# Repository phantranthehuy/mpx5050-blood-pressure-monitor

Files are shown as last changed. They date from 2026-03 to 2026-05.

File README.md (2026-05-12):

# 🩺 Digital Oscillometric Blood Pressure Monitor

> An academic research project focused on designing and developing a digital blood pressure monitor using the **MPX5050** pressure sensor and the **Oscillometric Method**.

## 📖 Table of Contents
- [About the Project](#about-the-project)
- [Key Features](#key-features)
- [Team Members](#team-members)
- [System Architecture](#system-architecture)
- [Technology Stack](#technology-stack)
- [Repository Structure](#repository-structure)
- [Getting Started](#getting-started)
- [License](#license)

## 🔬 About the Project
This repository contains the hardware schematics, embedded C firmware, and signal processing algorithms for an automated blood pressure monitor. 

The system operates based on the **Oscillometric Method**. It extracts tiny pressure oscillations (AC component) superimposed on the static cuff pressure (DC component) during the deflation phase. By analyzing the envelope of these oscillations, the system calculates the Mean Arterial Pressure (MAP), Systolic Pressure (SYS), Diastolic Pressure (DIA), and Heart Rate (BPM).

## ✨ Key Features
- **Automated Cuff Control:** Smooth inflation and linear deflation using a DC pump and a solenoid valve.
- **High-Precision Sensing:** Utilizes the MPX5050DP sensor with a custom Analog Front-End (AFE) for signal amplification and band-pass filtering (0.5Hz - 5Hz).
- **DSP Algorithms:** Implements digital filtering and envelope detection algorithms to accurately identify blood pressure parameters.
- **User Interface:** Real-time pressure monitoring and final result display via an LCD/OLED screen.

## 👥 Team Members
| Name | Role | Responsibilities |
| :--- | :--- | :--- |
| **Phan Tran The Huy** | **Project Manager & Hardware Lead** | Overall project management, Altium/KiCad schematic & PCB design, and hardware integration. |
| **Tran Nhat Ly** | **Mechanical & UI/UX Engineer** | 3D enclosure design, mechanical assembly, component sourcing, and UI programming. |
| **Nguyen Huy Hoang** | **DSP Algorithm & Research Lead** | Signal processing research (Kalman/FIR filters), data analysis, and technical documentation. |
| **Cao Hoang Tung** | **Embedded Software Engineer** | STM32 C programming, Pump/Valve driver implementation, and translating MATLAB/Python algorithms into embedded C. |

## 📐 System Architecture

The core of the system relies on capturing and separating the pressure signals:

## 🛠 Technology Stack
- **Microcontroller:** STM32 Series
- **Firmware:** C (STM32 HAL, CMake) trong `firmware/stm32-hal-cmake/`; tùy chọn C/C++ Arduino (STM32duino) trong `firmware/stm32-arduino-pio/`.
- **Development Environment:** VS Code with STM32CubeIDE Extension (HAL) hoặc VS Code + PlatformIO (Arduino, `firmware/stm32-arduino-pio/`).
- **Hardware Design:** Altium Designer / KiCad
- **Simulation Tools:** LTSpice (Analog filtering), Python/MATLAB (Algorithm verification)

## 📂 Repository Structure
```text
📦 mpx5050-blood-pressure-monitor
 ┣ 📂 Algorithms      # Python/MATLAB scripts for algorithm simulation & signal filtering
 ┣ 📂 Docs            # Datasheets, academic papers, and technical reports
 ┣ 📂 firmware        # stm32-hal-cmake (CMake+HAL) + stm32-arduino-pio (PlatformIO Arduino)
 ┣ 📂 Hardware        # Schematics, PCB layouts, and Bill of Materials (BOM)
 ┣ 📂 Mechanical      # 3D models and CAD files for the device enclosure
 ┣ 📜 .gitignore      # Ignored files for STM32, VS Code, and EDA tools
 ┣ 📜 LICENSE         # MIT License
 ┗ 📜 README.md       # Project documentation
```

## 🚀 Getting Started

### Prerequisites
- **VS Code** installed with the `C/C++` and `STM32 VS Code Extension`.
- **STM32CubeMX** (for modifying microcontroller pinouts/clocks).
- **Git** for version control.

### Installation & Build
1. **Clone the repository:**
   ```bash
   git clone https://github.com/your-username/mpx5050-blood-pressure-monitor.git
   ```
2. **Open the firmware (HAL / CMake):**
   Open the `firmware/stm32-hal-cmake` directory in VS Code (CMake + STM32 HAL).
3. **Optional — Arduino framework (same MCU):**
   Open `firmware/stm32-arduino-pio` in VS Code with the PlatformIO extension, or run `pio run` from that folder (see `firmware/stm32-arduino-pio/README.md`).
4. **Compile:**
   Press `Ctrl + Shift + B` (or use the STM32 extension build button) to compile the C code and generate the `.elf` / `.hex` files.
5. **Flash to MCU:**
   Connect your ST-Link debugger and click `Run > Start Debugging` (F5) to flash the firmware onto the STM32.

## ⚖️ License
This project is licensed under the **MIT License** - see the [LICENSE](LICENSE) file for details. Designed for academic and research purposes.

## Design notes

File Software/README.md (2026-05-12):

# Software — tài liệu host & WebApp

Thư mục này chứa tài liệu giao thức UART dùng chung với firmware và ứng dụng web đọc **USB TTL** (Web Serial).

## WebApp (Vite + TypeScript)

**Trình duyệt:** Chrome hoặc Edge (Web Serial). Phục vụ qua `http://localhost` hoặc HTTPS.

```bash
cd webapp
npm install
npm run dev
```

- Giao thức `S/A/E`, `T` và **MAA** trên host: [`pc-bridge.md`](pc-bridge.md), [`algorithm.md`](algorithm.md).
- Nút **Hủy** gửi `ABORT`; ô **SAF test** gửi `T,...` (clamp theo SAF đã cấu hình trên MCU / form, mặc định 175 mmHg). Sau kết nối, WebApp gửi `SAF` / `SAFH` / `HIGH` theo form **MCU — UART**.
- **Firefox/Safari** không có Web Serial: có thể dùng bridge TCP như gợi ý trong [`pc-bridge.md`](pc-bridge.md) (`socat`/nhỏ script đọc COM và WebSocket) rồi mở rộng webapp sau nếu cần.

## Firmware (tham chiếu)

Có hai biến thể cho **STM32F103C8 Blue Pill**, cùng chân và giao thức serial với WebApp:

| Thư mục | Công cụ | Ghi chú |
|---|---|---|
| [`../firmware/stm32-hal-cmake/`](../firmware/stm32-hal-cmake/) | CMake + STM32 HAL | Bản gốc trong repo; build theo [`../firmware/stm32-hal-cmake/README.md`](../firmware/stm32-hal-cmake/README.md). |
| [`../firmware/stm32-arduino-pio/`](../firmware/stm32-arduino-pio/) | PlatformIO + **Arduino** framework | `Wire` / `Serial` / `HardwareTimer`; xem [`../firmware/stm32-arduino-pio/README.md`](../firmware/stm32-arduino-pio/README.md). |

### Build & nạp (HAL — CMake)

```bash
cd ../firmware/stm32-hal-cmake
cmake --preset Debug
cmake --build build/Debug
```

### Build & nạp (Arduino — PlatformIO)

```bash
cd ../firmware/stm32-arduino-pio
pio run
pio run -t upload
pio device monitor -b 115200
```

Cần [PlatformIO Core](https://platformio.org/install) và ST-Link (hoặc đổi `upload_protocol` trong [`../firmware/stm32-arduino-pio/platformio.ini`](../firmware/stm32-arduino-pio/platformio.ini)).

### Cấu hình phần cứng

Chân mặc định xem [`../firmware/stm32-hal-cmake/Core/Inc/board_config.h`](../firmware/stm32-hal-cmake/Core/Inc/board_config.h) (HAL) hoặc `board_config.h` trong project Arduino (cùng map chân):

- UART1 **115200**: PA9 TX, PA10 RX  
- I2C1: PB6 SCL, PB7 SDA (ADS1115 `0x48`)  
- PWM TIM3: PA6 bơm, PA7 van  
- Nút (active LOW): PA3 Start, PA4 Stop, PA5 High-mode  
- LED schematic D401/D402/D403: **PB13 đỏ**, **PB14 xanh**, **PB15 vàng**

Hiệu chỉnh `PRESSURE_ADC_OFFSET_COUNTS` và `PRESSURE_ADC_SCALE_MMHG_PER_COUNT` theo MPX5050 + đồng hồ áp.

## Giao tiếp WebApp / serial

Chi tiết khung tin, band-pass 0.5–5 Hz trên host, và luồng `P_sys_est` → lệnh `T,...`: [**pc-bridge.md**](pc-bridge.md).

## Kiểm thử

Checklist mở rộng: [**TESTING.md**](TESTING.md), tham chiếu [`testcase.md`](testcase.md).

## LED (HMI)

Logic không chặn theo [`LED_Algorithm.md`](LED_Algorithm.md); phần C trong firmware HAL: [`../firmware/stm32-hal-cmake/Core/Inc/led_hmi.h`](../firmware/stm32-hal-cmake/Core/Inc/led_hmi.h), [`../firmware/stm32-hal-cmake/Core/Src/led_hmi.c`](../firmware/stm32-hal-cmake/Core/Src/led_hmi.c), ánh xạ trạng thái trong [`../firmware/stm32-hal-cmake/Core/Src/bp_fsm.c`](../firmware/stm32-hal-cmake/Core/Src/bp_fsm.c) (`bp_fsm_led_hmi_state`). Bản Arduino dùng cùng thuật toán LED trong `src/led_hmi.cpp`.

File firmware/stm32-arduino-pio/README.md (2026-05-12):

# Firmware Arduino — STM32F103 Blue Pill (PlatformIO)

Đây là **port song song** với bản CMake + HAL trong [`../stm32-hal-cmake/`](../stm32-hal-cmake/): cùng **STM32F103C8T6**, cùng map chân và **cùng giao thức UART** với WebApp/PC (xem [`../stm32-hal-cmake/docs/pc-bridge.md`](../stm32-hal-cmake/docs/pc-bridge.md)).

**Lưu ý:** Khi đổi thuật toán đo / FSM, nên coi bản **HAL CMake** là chuẩn tham chiếu rồi đồng bộ sang thư mục này (hoặc ngược lại — nhưng tránh chỉ sửa một bên).

## Công cụ

- [PlatformIO Core](https://platformio.org/install) (`python3 -m pip install --user platformio`)
- Nạp: **ST-Link** (mặc định `upload_protocol = stlink` trong [`platformio.ini`](platformio.ini)); có thể đổi sang `serial` nếu dùng bootloader UART.

## Build & nạp

```bash
cd firmware/stm32-arduino-pio
python3 -m platformio run
python3 -m platformio run -t upload
python3 -m platformio device monitor -b 115200
```

## Map chân (trùng HAL)

Định nghĩa trong [`src/board_pins.h`](src/board_pins.h) và hằng số áp suất trong [`src/board_config.h`](src/board_config.h):

| Chức năng | Chân |
|---|---|
| UART1 115200 | PA9 TX, PA10 RX (`Serial`) |
| I2C1 (ADS1115 `0x48`) | PB6 SCL, PB7 SDA (`Wire`) |
| PWM bơm / van | PA6, PA7 (`analogWrite`, 1 kHz) |
| Nút (active LOW, pull-up) | PA3 Start, PA4 Stop, PA5 High |
| LED | PB13 đỏ, PB14 xanh, PB15 vàng |

## Khác biệt so với bản HAL

- **ADS1115:** driver dùng `Wire` (địa chỉ 7-bit), không dùng `HAL_I2C_*`.
- **UART:** `Serial` + `uart_proto_poll_rx()` trong vòng lặp (polling), tương đương luồng lệnh `T,...` / `ABORT` / `DR,...` / `EARLYEND` khi đã đồng bộ với bản HAL.
- **100 Hz:** `HardwareTimer` trên **TIM2** (`setOverflow(100, HERTZ_FORMAT)`).
- **PWM:** `analogWriteFrequency(1000)` (toàn cục trên core STM32duino) + `analogWriteResolution(10)` + `analogWrite` — tương đương duty 0–100 % của HAL.

## Giao thức host

Giữ nguyên định dạng dòng `S,...`, `A,...`, `E,...` và lệnh `T,<mmHg>` như tài liệu `pc-bridge.md` ở bản HAL. Thêm: **`DR,<mmHg/s>`** (tốc độ xả chậm đo, clamp theo `DEFLATE_SLOW_RATE_UART_*` trong `board_config.h`, hiện 2.5–10.0 mmHg/s) và **`EARLYEND`** (kết thúc xả chậm sớm → xả nhanh, chỉ trong pha đo). Dòng **`S,...`** đầy đủ kết thúc bằng **`,<dp_centi>`** — `dp_centi = round(dp/dt mmHg/s × 100)` (âm khi áp giảm); WebApp parse thành `dpMmHgPerS`.

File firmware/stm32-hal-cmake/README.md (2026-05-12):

# Firmware — máy đo huyết áp oscillometric (STM32F103 Blue Pill)

Project **STM32Cube / CMake** (HAL): đọc áp **ADS1115** (I2C), điều khiển **bơm/van PWM**, stream **100 Hz** qua UART cho WebApp/PC, SAF mặc định **175 mmHg** (có thể đổi UART `SAF` / `SAFH`) và **Emergency Stop** cục bộ.

## Build & nạp

Cần **CMake ≥ 3.22**, **GNU Arm Embedded Toolchain** (`arm-none-eabi-gcc`), và **Git** (lần cấu hình đầu CMake sẽ clone HAL/CMSIS vào `third_party/`).

```bash
cd firmware/stm32-hal-cmake
cmake --preset Debug
cmake --build build/Debug
```

File nhị phân: `build/Debug/bp_monitor.bin`, ELF `build/Debug/bp_monitor`.

**STM32CubeIDE for VS Code:** mở folder `firmware/stm32-hal-cmake`, chọn preset **Debug** hoặc **Release**, chạy CMake configure/build trong extension theo [First project creation](https://dev.st.com/stm32cube-docs/stm32cubeide-vscode/1.0.1/en/docs/markup/getting_started/first_project_creation.html).

**Bản Arduino (PlatformIO, thư viện Wire/Serial):** xem [`../stm32-arduino-pio/README.md`](../stm32-arduino-pio/README.md).

**Nạp chip:** dùng `stm32flash`, OpenOCD, hoặc STM32CubeProgrammer tới địa chỉ flash `0x08000000`, ví dụ:

```bash
stm32flash -w build/Debug/bp_monitor.bin -v -g 0x0 /dev/ttyUSB0   # tuỳ adapter UART bootloader
```

**UART serial:** `115200 8N1` trên USART1 (PA9/PA10).

### STM32F103C8T6 (Blue Pill)

Không cần đổi macro biên dịch: ST dùng **`STM32F103xB`** trong CMSIS cho cả **C8** và **CB** (file chip là `stm32f103xb.h`). Điều quan trọng là **kích thước Flash trong linker**:

| MCU | Flash | Việc cần làm |
|-----|---|---|
| **STM32F103C8T6** | 64 KiB | Giữ nguyên `cmake/STM32F103C8Tx_FLASH.ld` (đã cấu hình sẵn). |
| **STM32F103CB…** | 128 KiB | Đổi `LENGTH` Flash trong linker script thành `128K` (hoặc dùng script ST cho RB/CB 128K). |

## Cấu hình phần cứng

Chân mặc định xem [`Core/Inc/board_config.h`](Core/Inc/board_config.h):

- UART1 **115200**: PA9 TX, PA10 RX  
- I2C1: PB6 SCL, PB7 SDA (ADS1115 `0x48`)  
- PWM TIM3: PA6 bơm, PA7 van  
- Nút (active LOW): PA3 Start, PA4 Stop, PA5 High-mode  
- LED schematic D401/D402/D403: **PB13 đỏ**, **PB14 xanh**, **PB15 vàng**

Hiệu chỉnh `PRESSURE_ADC_OFFSET_COUNTS` và `PRESSURE_ADC_SCALE_MMHG_PER_COUNT` theo MPX5050 + đồng hồ áp.

## Giao tiếp WebApp / serial

Chi tiết khung tin, band-pass 0.5–5 Hz trên host, và luồng `P_sys_est` → lệnh `T,...`: [**docs/pc-bridge.md**](docs/pc-bridge.md).

## Kiểm thử

Checklist mở rộng: [**TESTING.md**](TESTING.md), tham chiếu [`testcase.md`](testcase.md).

## LED (HMI)

Logic không chặn theo [`LED_Algorithm.md`](LED_Algorithm.md); code: [`Core/Inc/led_hmi.h`](Core/Inc/led_hmi.h), [`Core/Src/led_hmi.c`](Core/Src/led_hmi.c), ánh xạ trạng thái trong [`Core/Src/bp_fsm.c`](Core/Src/bp_fsm.c) (`bp_fsm_led_hmi_state`).

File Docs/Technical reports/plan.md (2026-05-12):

# Dàn ý báo cáo — Máy đo huyết áp oscillometric (MPX5050 + STM32)

## Thông tin (điền vào `Project_report/main.tex`)

- **Môn / loại báo cáo:** Đồ án / báo cáo môn học EE3037 (điều chỉnh nếu khác).
- **Đề tài:** Thiết kế máy đo huyết áp điện tử phương pháp oscillometric dựa trên cảm biến áp MPX5050, ADC ADS1115 và vi điều khiển STM32F103; phần mềm host Web Serial để lọc tín hiệu và tính MAP/SBP/DBP (MAA).
- **GVHD:** *(điền tên)*  
- **SVTH / MSSV:** *(điền)*  

## Cấu trúc chương (ánh xạ file LaTeX)

1. **Chương 1 — Giới thiệu** (`chap1.tex`)  
   - Tổng quan bài toán đo huyết áp không xâm lấn.  
   - Phương pháp oscillometric, vai trò cuff–cảm biến–MCU–host.  
   - Nhiệm vụ đề tài (phần cứng, firmware, WebApp, an toàn SAF).  
   - Bố cục báo cáo.

2. **Chương 2 — Phần cứng** (`chap2.tex`)  
   - Sơ đồ khối: MPX5050 → điều kiện tín hiệu → ADS1115 (I2C) → STM32.  
   - Điều khiển bơm/van PWM; nút Start/Stop/High; LED trạng thái.  
   - Tham chiếu schematic/PCB (in từ KiCad — file ảnh/PDF trong `images/`).  
   - Giới hạn an toàn: trần áp 280 mmHg (SAF).

3. **Chương 3 — Firmware và thuật toán** (`chap3.tex`)  
   - Kiến trúc PlatformIO / STM32Cube; đọc áp; stream UART 100 Hz (`S,...`).  
   - FSM đo: bơm chậm, lệnh `T,...` từ host, xả chậm đo.  
   - Cơ sở MAA trên host: envelope, MAP, hệ số \(r_s\), \(r_d\) cho SBP/DBP; band-pass 0,5–5 Hz (theo tài liệu nội bộ).  
   - Hiệu chỉnh offset/scale ADC → mmHg.

4. **Chương 4 — Phần mềm host và kiểm thử** (`chap4.tex`)  
   - WebApp (Vite + TypeScript), Web Serial; giao thức `A/E/T/ABORT`.  
   - Luồng `P_\mathrm{sys\,est}` → `T,...`; clamp SAF.  
   - Checklist kiểm thử (UART, LED, SAF, leak timeout).

5. **Kết luận** (`ketluan.tex`)  
   - Kết quả đạt được; hạn chế (hiệu chỉnh, chỉ số MAA cố định); hướng phát triển.

6. **Tài liệu tham khảo** (`tlthamkhao.tex`)  
   - Datasheet NXP MPX5050, TI ADS111x, RM/STM32F103; tài liệu oscillometry / MAA nếu có.

## Hình ảnh đính kèm trong `Project_report/images/`

- `logo-bku.png` — logo trường (bìa).  
- `Print.pdf` — bản in schematic/board (nếu có).  
- `webapp-hero.png` — minh họa giao diện WebApp (tùy chọn).

## Biên dịch

Dùng **XeLaTeX** (class có `fontspec`). Ví dụ: `latexmk -xelatex main.tex` trong thư mục `Project_report`.

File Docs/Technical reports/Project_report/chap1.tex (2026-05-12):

%===============================================================
% chap1.tex — Chương 1: Giới thiệu
%===============================================================
\pagestyle{fancy}
\chapter{GIỚI THIỆU}

\section{Tổng quan đề tài}
Đo huyết áp động mạch là một trong các chỉ số sinh lý quan trọng trong chẩn đoán và theo dõi bệnh tim mạch. Trong thực hành lâm sàng cổ điển, phương pháp Korotkoff kết hợp máy đo thủy ngân và ống nghe cho phép xác định áp tâm thu (SBP) và áp tâm trương (DBP) nhờ âm thanh nghe được khi xả khí vòng bít. Máy đo điện tử hiện đại phổ biến thay thế tai nghe bằng việc phân tích dao động áp suất nhỏ trên nền áp suất bao (\textit{oscillometric}), phù hợp với phần cứng chi phí thấp và tái lập trình.

Đề tài xây dựng một nguyên mẫu máy đo oscillometric với các đặc điểm sau:
\begin{itemize}\itemsep0pt \parskip0pt \parsep0pt
	\item \textbf{Cảm biến áp:} MPX5050GP (đầu ra tương tự thuận tiện khuếch đại/đọc ADC).
	\item \textbf{Bộ chuyển đổi số:} ADS1115 độ phân giải 16-bit, giao tiếp I\textsuperscript{2}C với STM32F103.
	\item \textbf{Điều khiển khí nén:} bơm và van được điều chỉnh bằng PWM để đạt tốc độ bơm và xả mong muốn.
	\item \textbf{An toàn:} giới hạn áp suất cực đại 280~mmHg (SAF), dừng khẩn cấp nút cứng và lệnh serial \texttt{ABORT}.
	\item \textbf{Host:} WebApp đọc cổng serial (Web Serial), hiển thị sóng áp và thực hiện lọc số + thuật toán MAA để suy ra MAP, SBP, DBP.
\end{itemize}

\section{Nhiệm vụ đề tài}
\noindent\textbf{Nội dung 1: Phần cứng và bo mạch (OscilloBP Monitor).}\\
\vspace{-0.6cm}
\begin{itemize}\itemsep0pt \parskip0pt \parsep0pt
	\item \textbf{Mục tiêu:} Hoàn thiện mạch đo áp, MCU, điều khiển bơm/van, nút nhấn và LED trạng thái theo schematic/PCB trong kho mã.
	\item \textbf{Ý tưởng thực hiện:} MPX5050 cấp điện áp tỉ lệ áp suất; ADS1115 lấy mẫu ổn định hơn ADC nội Blue Pill; STM32 điều phối FSM đo và streaming UART.
\end{itemize}
\vspace{-0.2cm}

\noindent\textbf{Nội dung 2: Firmware STM32 (PlatformIO / STM32Cube).}\\
\vspace{-0.6cm}
\begin{itemize}\itemsep0pt \parskip0pt \parsep0pt
	\item \textbf{Mục tiêu:} Đọc áp liên tục trong các pha đo, điều khiển bơm/van theo tốc độ đặt trước, đồng bộ với lệnh \texttt{T,...} từ host.
	\item \textbf{Ý tưởng thực hiện:} Máy trạng thái gồm các pha bơm chậm (nghe dao động), ramp margin, xả chậm đo, xả nhanh kết thúc hoặc an toàn; định dạng khung \texttt{S,<seq>,<t\_ms>,<p\_mmHg>} và thông báo \texttt{A,...}, \texttt{E,...}.
\end{itemize}
\vspace{-0.2cm}

\noindent\textbf{Nội dung 3: Phần mềm host và kiểm chứng.}\\
\vspace{-0.6cm}
\begin{itemize}\itemsep0pt \parskip0pt \parsep0pt
	\item \textbf{Mục tiêu:} Hiển thị thời gian thực, lọc dao động, tính MAP/SBP/DBP bằng MAA; kiểm thử UART, LED và SAF.
	\item \textbf{Ý tưởng thực hiện:} Band-pass 0{,}5--5~Hz trên chuỗi áp; phát hiện dao động đầu tiên trong pha bơm chậm để ước lượng \texttt{P\_sys\_est} và gửi \texttt{T,P\_sys\_est+margin}.
\end{itemize}

\section{Bố cục báo cáo}
Ngoài phần đầu (tóm tắt, mục lục, danh mục hình/bảng và viết tắt), báo cáo gồm bốn chương chính và phần kết luận. \textbf{Chương 2} trình bày kiến trúc phần cứng và hình ảnh schematic/in PCB. \textbf{Chương 3} mô tả firmware, giao thức serial và cơ sở thuật toán oscillometric/MAA được triển khai trên host. \textbf{Chương 4} giới thiệu WebApp và checklist kiểm thử. \textbf{Kết luận} tóm tắt kết quả, hạn chế và hướng phát triển.

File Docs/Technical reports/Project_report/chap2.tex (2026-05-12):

%===============================================================
% chap2.tex — Phần cứng
%===============================================================
\pagestyle{fancy}
\chapter{CƠ SỞ PHẦN CỨNG}

\section{Sơ đồ khối chức năng}
Hệ thống gồm các khối sau:
\begin{enumerate}\itemsep0pt
	\item \textbf{Vòng bít và đường khí nối:} chứa áp suất làm xẹp động mạch và truyền áp tới cảm biến.
	\item \textbf{Cảm biến MPX5050:} chuyển áp suất tương đối thành điện áp tương tự (khảo sát đường đặc tuyến trong datasheet).
	\item \textbf{ADC ADS1115:} chuyển đổi điện áp với độ phân giải 16-bit; giao tiếp I\textsuperscript{2}C với MCU (địa chỉ thiết bị mặc định 0x48 khi chân ADDR nối GND).
	\item \textbf{Vi điều khiển STM32F103 (Blue Pill):} đọc ADS1115, điều khiển PWM bơm và van, đọc nút nhấn, điều khiển LED và truyền thông UART.
	\item \textbf{Nguồn và điều kiện tiếp đất:} đảm bảo MPX5050 và ADC có tham chiếu ổn định; layout PCB tuân thủ khuyến nghị của nhà sản xuất để giảm nhiễu đo lường.
\end{enumerate}

\section{Giao tiếp và chân cắm chính}
Theo cấu hình mặc định trong firmware (\texttt{board\_config.h}):
\begin{itemize}\itemsep0pt
	\item UART1 115200~bps: PA9 (TX), PA10 (RX).
	\item I2C1: PB6 (SCL), PB7 (SDA) nối ADS1115.
	\item Timer 3 PWM: PA6 kênh bơm, PA7 kênh van (điều chỉnh duty để servo tốc độ bơm/xả).
	\item Nút tác động mức thấp (kéo lên nội bộ): PA3 Start, PA4 Stop, PA5 High-mode.
	\item LED báo hiệu: PB13 đỏ, PB14 xanh, PB15 vàng (ánh xạ trạng thái đo và cảnh báo).
\end{itemize}

\section{An toàn và giới hạn vật lý}
\begin{itemize}\itemsep0pt
	\item Trần áp \textbf{280~mmHg}: firmware ngắt bơm và mở van để xả nhanh khi vượt ngưỡng hoặc khi người dùng nhấn Stop/\texttt{ABORT}.
	\item Timeout rò khí: nếu áp không tăng đủ trong khoảng thời gian đặt (ví dụ rò đường khí), FSM báo lỗi cảm biến/rò và chuyển LED đỏ báo lỗi.
\end{itemize}

\section{Schematic và PCB}
Thiết kế schematic và bản vẽ PCB được hoàn thiện trong dự án KiCad \textit{OscilloBP Monitor}. Hình~\ref{fig:schematic-print} trích bản in PDF trong kho mã (có thể thay bằng ảnh độ phân giải cao hơn khi cần in báo cáo).

\begin{figure}[htbp]
	\centering
	
	\caption{Bản in schematic/board (trích từ dự án KiCad OscilloBP Monitor).}
	\label{fig:schematic-print}
\end{figure}

\section{Nhiệm vụ hiệu chỉnh phần cứng}
Để đọc mmHg chính xác từ ADC, cần hiệu chỉnh hai tham số trong firmware: \texttt{PRESSURE\_ADC\_OFFSET\_COUNTS} và \texttt{PRESSURE\_ADC\_SCALE\_MMHG\_PER\_COUNT} so với đồng hồ áp chuẩn hoặc nguồn áp đã biết. Đây là bước bắt buộc trước khi đánh giá lâm sàng.

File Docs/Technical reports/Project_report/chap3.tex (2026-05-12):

%===============================================================
% chap3.tex — Firmware và thuật toán
%===============================================================
\pagestyle{fancy}
\chapter{FIRMWARE VÀ THUẬT TOÁN OSCILLOMETRIC}

\section{Kiến trúc phần mềm nhúng}
Firmware được xây dựng bằng PlatformIO, board \texttt{bluepill\_f103c8}, framework STM32Cube HAL. Các module chính:
\begin{itemize}\itemsep0pt
	\item Driver ADS1115 đọc kênh vi sai phù hợp với điện áp ra của MPX5050 và PGA đặt trong phạm vi đầy thang không bão hòa.
	\item Chuyển đổi đếm ADC \(\rightarrow\) áp suất cuff (mmHg) bằng offset và hệ số scale (hiệu chỉnh thực nghiệm).
	\item FSM đo huyết áp: pha bơm chậm có ``nghe'' dao động; pha ramp đến mục tiêu sau lệnh host; pha xả chậm để thu sóng oscillometric; pha xả nhanh kết thúc hoặc an toàn.
	\item UART text-line: stream mẫu và thông báo trạng thái cho WebApp.
\end{itemize}

\section{Luồng đo và giao thức UART}
Bảng~\ref{tab:uart-frames} tóm tắt các khung điển hình (chi tiết trong tài liệu \texttt{pc-bridge.md} của kho mã).

\begin{table}[htbp]
	\centering
	\caption{Các dòng lệnh/thông báo UART tiêu biểu.}
	\label{tab:uart-frames}
	\begin{tabular}{ll}
		\hline
		\textbf{Dòng} & \textbf{Ý nghĩa} \\
		\hline
		\texttt{S,<seq>,<t\_ms>,<p\_mmHg>} & Stream áp suất (~100 Hz trong đo) \\
		\texttt{A,IDLE} / \texttt{A,INFLATE\_SLOW} / \texttt{A,DEFLATE} & Trạng thái FSM \\
		\texttt{T,<target\_mmHg>} & Host đặt áp mục tiêu (clamp \(\leq\) SAF) \\
		\texttt{ABORT} hoặc \texttt{A} & Yêu cầu xả nhanh an toàn \\
		\texttt{E,MEAS\_END} & Kết thúc đo \\
		\hline
	\end{tabular}
\end{table}

Tốc độ nền: baud 115200, kết thúc dòng \texttt{\textbackslash r\textbackslash n}. Trần SAF \textbf{280~mmHg} áp dụng đồng nhất cho điều khiển cục bộ và clamp lệnh \texttt{T,...}.

\section{Cơ sở thuật toán MAA trên host}
Thuật toán biên độ cực đại (MAA) làm việc trên đường bao dao động (OWE) của thành phần AC của áp suất cuff trong quá trình xả chậm:
\begin{enumerate}\itemsep0pt
	\item Xác định \(\mathrm{MAP}\) là áp suất cuff tại điểm biên độ dao động cực đại \(A_{\max}\).
	\item Với các hệ số đặc trưng \(r_s\) (tâm thu) và \(r_d\) (tâm trương), tính các mức biên độ mục tiêu \(A_{\mathrm{sys}} = r_s A_{\max}\), \(A_{\mathrm{dia}} = r_d A_{\max}\).
	\item Dò nhánh áp cao hơn MAP để tìm điểm gần \(A_{\mathrm{sys}}\) \(\Rightarrow\) SBP; dò nhánh áp thấp hơn MAP để tìm điểm gần \(A_{\mathrm{dia}}\) \(\Rightarrow\) DBP.
\end{enumerate}

Trên host, trước khi trích envelope và cực đại, tài liệu kỹ thuật dự án khuyến nghị \textbf{lọc số dải thông 0{,}5--5~Hz} để giữ nhịp mạch và giảm nhiễu tay/run.

\section{Đồng bộ với pha bơm chậm}
Trong pha \texttt{INFLATE\_SLOW}, WebApp theo dõi dao động sau lọc để ước lượng \(\mathrm{P\_sys\_est}\). Sau đó host gửi \(\texttt{T},\mathrm{P\_sys\_est}+40\) (margin mặc định trong \texttt{board\_config.h}) để MCU ramp đến mục tiêu rồi chuyển xả chậm đo. Nếu không có host trong thời gian chờ, firmware có thể ramp theo mục tiêu dự phòng (\texttt{INFLATE\_FALLBACK\_TARGET\_MMHG}).

\section{LED và trải nghiệm người dùng}
LED phản ánh trạng thái không chặn luồng đo (tham chiếu \texttt{LED\_Algorithm.md}): idle/done xanh; bơm margin vàng nhấp nháy; đo/xả vàng sáng; STOP/SAF/\texttt{ABORT} đỏ nhấp nháy nhanh; lỗi rò/I2C đỏ sáng.

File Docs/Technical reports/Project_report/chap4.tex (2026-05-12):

%===============================================================
% chap4.tex — Phần mềm host và kiểm thử
%===============================================================
\pagestyle{fancy}
\chapter{PHẦN MỀM HOST VÀ KIỂM THỬ}

\section{WebApp và Web Serial}
Ứng dụng web (\texttt{Software/webapp}) dùng Vite và TypeScript, chạy trên trình duyệt Chrome hoặc Edge với API Web Serial để mở cổng USB--TTL nối UART của MCU. Giao diện hiển thị sóng áp thời gian thực và các nút điều khiển (\textbf{Hủy} gửi \texttt{ABORT}; ô kiểm SAF có thể minh họa clamp khi gửi \texttt{T,300}).

\begin{figure}[htbp]
	\centering
	
	\caption{Minh họa giao diện WebApp (ảnh hero trong kho mã).}
	\label{fig:webapp}
\end{figure}

\section{Xử lý tín hiệu trên host}
Luồng xử lý khuyến nghị:
\begin{enumerate}\itemsep0pt
	\item Thu thập chuỗi mẫu áp từ các dòng \texttt{S,...}.
	\item Áp dụng lọc dải thông 0{,}5--5~Hz để cô lập dao động pulsatile.
	\item Trong bơm chậm: phát hiện dao động đạt ngưỡng đủ lớn để ghi \(\mathrm{P\_sys\_est}\).
	\item Gửi \(\texttt{T},\mathrm{P\_sys\_est}+\mathrm{margin}\) xuống MCU.
	\item Trong xả chậm: xây envelope và chạy MAA để hiển thị MAP/SBP/DBP.
\end{enumerate}

\section{Kiểm thử được khuyến nghị}
Checklist trong \texttt{Firmware/TESTING.md} và \texttt{Firmware/testcase.md} hướng dẫn các nhóm thử:

\noindent\textbf{Nhóm an toàn (SAF):}
\begin{itemize}\itemsep0pt
	\item STOP khi đang bơm: bơm tắt ngay, van mở tối đa, LED đỏ nhấp nháy nhanh.
	\item Trần 280~mmHg: MCU cắt bơm và báo động.
	\item Lệnh \texttt{T,300}: firmware clamp về 280.
	\item \texttt{ABORT}/\texttt{A}: xả nhanh như STOP phần cứng về hành vi an toàn.
\end{itemize}

\noindent\textbf{Nhóm UART:}
\begin{itemize}\itemsep0pt
	\item Kiểm tra ~100 khung \texttt{S,...}/giây trong inflate/deflate.
	\item Sau \texttt{T,...}, MCU vào margin rồi xả đo đúng trình tự.
\end{itemize}

\noindent\textbf{Nhóm LED/HMI:} idle xanh; inflate vàng nhấp nháy \(\sim\)500~ms; đo/xả vàng sáng; STOP/SAF/fast deflate đỏ nhấp nháy \(\sim\)150~ms; lỗi rò/I2C đỏ sáng.

\section{Hạn chế của kiểm thử trong phòng lab}
 Firefox/Safari không hỗ trợ Web Serial; có thể cần bridge TCP/\texttt{socat} nếu phải dùng trình duyệt khác. Đánh giá độ chính xác lâm sàng đòi hiệu chỉnh đồng hồ áp và mẫu đối chứng đủ lớn, nằm ngoài phạm vi một checklist chức năng thuần túy.

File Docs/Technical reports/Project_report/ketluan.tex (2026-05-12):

%===============================================================
% ketluan.tex — Kết luận
%===============================================================
\chapter*{{\Large\begin{center}KẾT LUẬN\end{center}}}
\addcontentsline{toc}{chapter}{Kết luận}

\section*{Kết quả đạt được}
Đề tài đã xây dựng được một nguyên mẫu máy đo huyết áp oscillometric với đầy đủ các khối chức năng: cảm biến MPX5050, ADC ADS1115, vi điều khiển STM32F103 điều khiển bơm/van PWM và streaming UART; phần mềm WebApp trên trình duyệt hỗ trợ Web Serial để hiển thị sóng áp, lọc số và MAA nhằm suy ra MAP, SBP và DBP; cơ chế an toàn trần áp 280~mmHg và dừng khẩn cấp được triển khai đồng thời trên firmware và qua lệnh serial. Bo mạch và schematic được thể hiện trong dự án KiCad OscilloBP Monitor kèm Gerber phục vụ gia công.

\section*{Hạn chế}
Độ chính xác tuyệt đối phụ thuộc mạnh vào hiệu chỉnh offset/scale của kênh đo áp và vào bộ hệ số \(r_s\), \(r_d\) của MAA; các giá trị mặc định trong tài liệu chỉ mang tính tham chiếu và cần tinh chỉnh theo dữ liệu lâm sàng hoặc bộ phép đo chuẩn. Web Serial giới hạn loại trình duyệt; đo trong điều kiện chuyển động tay hoặc nhiễu điện từ có thể làm méo envelope nếu không bổ sung lọc/outlier mạnh hơn.

\section*{Hướng phát triển}
Áp dụng hiệu chỉnh đa điểm và lưu hệ số trên EEPROM; mở rộng thuật toán (khớp đường cong Gauss, thích ứng \(r_s,r_d\)); tích hợp bridge TCP/WebSocket cho đa nền tảng; thực hiện thử nghiệm so sánh với máy đo đã chứng nhận y tế và hoàn thiện hồ sơ an toàn điện/khí nén cho sản phẩm.

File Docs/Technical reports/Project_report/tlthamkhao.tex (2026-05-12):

% LTeX: enabled=false
%===============================================================
% tlthamkhao.tex — Tài liệu tham khảo
%===============================================================
\begin{thebibliography}{99}

	\bibitem{mpx5050}
	NXP Semiconductors,
	\textit{MPX5050 / MPX5050GP --- Integrated Silicon Pressure Sensor On-Chip Signal Conditioned, Temperature Compensated and Calibrated},
	Datasheet, truy cập qua trang nhà sản xuất.

	\bibitem{ads1115}
	Texas Instruments,
	\textit{ADS1113, ADS1114, ADS1115 --- Ultra-Small, Low-Power, I\textsuperscript{2}C-Compatible, 860-SPS ADC With Internal Reference},
	Datasheet SBAS444.

	\bibitem{stm32f103}
	STMicroelectronics,
	\textit{STM32F103x8 / STM32F103xB --- Medium-density performance line ARM-based 32-bit MCU},
	Reference Manual RM0008 và Datasheet DS5319.

	\bibitem{geddes}
	L.\ A.\ Geddes và M.\ Voelz,
	\textit{Pulse Transit Time as an Indicator of Arterial Blood Pressure},
	và các tài liệu cổ điển về oscillometry / characteristic ratios (tham khảo trong giáo trình đo lường y sinh).

	\bibitem{repo}
	Nhóm dự án,
	\textit{mpx5050-blood-pressure-monitor} --- firmware PlatformIO, WebApp và tài liệu nội bộ (\texttt{algorithm.md}, \texttt{pc-bridge.md}, \texttt{TESTING.md}),
	Kho mã nguồn GitHub \texttt{phantranthehuy/mpx5050-blood-pressure-monitor}, 2026.

\end{thebibliography}

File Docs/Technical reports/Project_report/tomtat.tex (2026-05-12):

%===============================================================
% tomtat.tex — Tóm tắt đề tài
%===============================================================
\begin{center}
	\textbf{{\Large\textcolor{black}{TÓM TẮT ĐỀ TÀI}}}
\end{center}

\vspace{1cm}

\hspace*{2cm}
Đề tài trình bày thiết kế một máy đo huyết áp điện tử theo phương pháp \textit{oscillometric}: áp suất trong băng được đo bằng cảm biến áp tuyến tính NXP MPX5050, chuyển đổi tương tự--số qua ADC ngoài Texas Instruments ADS1115 giao tiếp I\textsuperscript{2}C với vi điều khiển STM32F103 (Blue Pill). Firmware điều khiển bơm và van bằng PWM để bơm chậm, ramp đến mục tiêu và xả chậm trong khi đo; đồng thời truyền dòng dữ liệu áp suất khoảng 100 mẫu/giây qua UART (115200~bps) về máy tính.

Phần mềm host (WebApp Vite + TypeScript, Web Serial trên Chrome/Edge) lọc số dải thông 0{,}5--5~Hz, ước lượng áp tâm thu đại diện trong pha bơm chậm để gửi lệnh đặt áp mục tiêu \texttt{T,<mmHg>} xuống MCU; trong pha xả, máy chủ tạo đường bao dao động và áp dụng thuật toán biên độ cực đại (MAA) với các hệ số đặc trưng \(r_s\), \(r_d\) để suy ra MAP, SBP và DBP. Hệ thống có cơ chế an toàn cục bộ: trần áp 280~mmHg, dừng khẩn cấp nút cứng và lệnh \texttt{ABORT}, báo hiệu LED (đỏ/vàng/xanh) theo trạng thái đo.

Kết quả là một nguyên mẫu phần cứng--phần mềm thống nhất phục vụ đo và hiển thị trên trình duyệt; độ chính xác lâm sàng phụ thuộc hiệu chỉnh cảm biến và tinh chỉnh tham số MAA, được nêu trong kết luận và hướng phát triển.

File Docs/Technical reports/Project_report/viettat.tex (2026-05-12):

%===============================================================
% viettat.tex — Danh mục chữ viết tắt
%===============================================================
\begin{table}[h!]
	\centering
	\begin{tabular}{ll}
		ADC     & Analog-to-Digital Converter (bộ chuyển đổi tương tự--số) \\
		ADS1115 & Bộ ADC Sigma-Delta 16-bit (Texas Instruments) \\
		DBP     & Diastolic Blood Pressure (huyết áp tâm trương) \\
		FSM     & Finite State Machine (máy trạng thái hữu hạn) \\
		HMI     & Human--Machine Interface (giao diện người--máy) \\
		I\textsuperscript{2}C & Giao tiếp nối tiếp hai dây \\
		MAA     & Maximum Amplitude Algorithm (thuật toán biên độ cực đại) \\
		MAP     & Mean Arterial Pressure (huyết áp trung bình động mạch) \\
		MCU     & Microcontroller Unit (vi điều khiển) \\
		MPX5050 & Cảm biến áp tích hợp (NXP) \\
		OWE     & Oscillometric Waveform Envelope (đường bao dao động oscillometric) \\
		PWM     & Pulse Width Modulation (điều chế độ rộng xung) \\
		SAF     & Safety (an toàn -- giới hạn áp cực đại) \\
		SBP     & Systolic Blood Pressure (huyết áp tâm thu) \\
		UART    & Universal Asynchronous Receiver/Transmitter \\
	\end{tabular}
\end{table}

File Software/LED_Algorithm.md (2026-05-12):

Dựa trên các yêu cầu về hiệu ứng hiển thị và thông số chân vi điều khiển (PB13, PB14, PB15) từ Schematic, tôi đã viết lại **toàn bộ giải thuật điều khiển LED hoàn chỉnh, chuẩn mực cho vi điều khiển nhúng**.

Giải thuật này được nâng cấp thêm một tính năng cực kỳ quan trọng: **Nhận diện thay đổi trạng thái (State-change detection)**. Nghĩa là ngay khi người dùng bấm nút hoặc máy chuyển sang bước đo tiếp theo, đèn sẽ thay đổi NGAY LẬP TỨC mà không bị trễ, đồng thời hoàn toàn không dùng hàm `HAL_Delay()` để tránh làm treo hệ thống đo huyết áp.

Bạn có thể tạo một file riêng (VD: `led_hmi.c` và `led_hmi.h`) hoặc copy trực tiếp đoạn code này vào khu vực *User Code* trong file `main.c`.

### ĐOẠN CODE C ĐẦY ĐỦ (Dành cho STM32 HAL Library)

```c

#include "main.h"

// ====================================================================

// 1. KHAI BÁO CHÂN PHẦN CỨNG (Dựa theo Schematic trang 1)

// ====================================================================

#define LED_RED_PORT      GPIOB

#define LED_RED_PIN       GPIO_PIN_13     // D401

#define LED_GREEN_PORT    GPIOB

#define LED_GREEN_PIN     GPIO_PIN_14     // D402

#define LED_YELLOW_PORT   GPIOB

#define LED_YELLOW_PIN    GPIO_PIN_15     // D403

// ====================================================================

// 2. KHAI BÁO CHU KỲ NHẤP NHÁY (Thời gian bằng mili-giây)

// ====================================================================

#define BLINK_NORMAL_MS   500  // Nháy chậm (Bơm căng) - 500ms sáng, 500ms tắt

#define BLINK_FAST_MS     150  // Nháy nhanh (Khẩn cấp) - 150ms sáng, 150ms tắt

// ====================================================================

// 3. ĐỊNH NGHĨA TRẠNG THÁI HỆ THỐNG (ENUM)

// ====================================================================

typedef enum {

    SYS_STATE_IDLE = 0,    // Chờ / Sẵn sàng đo

    SYS_STATE_INFLATING,   // Đang bơm căng vòng bít (Đo cao huyết áp)

    SYS_STATE_MEASURING,   // Đang xả khí để lấy mẫu tính huyết áp

    SYS_STATE_ERROR,       // Lỗi đo (hở khí, rung tay...)

    SYS_STATE_EMERGENCY    // Dừng khẩn cấp (Người dùng ấn nút STOP)

} SystemState_t;

// Biến toàn cục đại diện cho trạng thái hiện tại của máy (bạn sẽ đổi biến này ở hàm khác)

SystemState_t current_sys_state = SYS_STATE_IDLE; 

// ====================================================================

// 4. HÀM CẬP NHẬT TRẠNG THÁI LED (Đặt vào trong vòng lặp while(1))

// ====================================================================

void LED_Update_Task(void) 

{

    // Các biến static giúp lưu giữ giá trị qua mỗi vòng lặp

    static uint32_t previous_tick = 0;

    static uint8_t  blink_flag = 0;

    static SystemState_t last_sys_state = 255; // Giá trị ảo ban đầu để ép làm mới trạng thái

    uint32_t current_tick = HAL_GetTick(); // Đọc bộ đếm thời gian thực của STM32

    uint8_t state_changed = 0;             // Cờ báo hiệu có sự chuyển đổi trạng thái

    // Nếu trạng thái máy vừa bị thay đổi (Vd: Bấm nút START chuyển từ IDLE -> INFLATING)

    if (current_sys_state != last_sys_state) 

    {

        state_changed = 1;

        last_sys_state = current_sys_state;

        // Reset lại thời gian và cờ nhấp nháy để đèn sáng/tắt ngay lập tức không bị trễ

        previous_tick = current_tick;

        blink_flag = 1; 

    }

    // Xử lý logic LED tùy theo trạng thái

    switch (current_sys_state) 

    {

        case SYS_STATE_IDLE:

            // Yêu cầu: Đèn Xanh lá SÁNG, các đèn khác TẮT

            if (state_changed) {

                HAL_GPIO_WritePin(LED_GREEN_PORT, LED_GREEN_PIN, GPIO_PIN_SET);

                HAL_GPIO_WritePin(LED_YELLOW_PORT, LED_YELLOW_PIN, GPIO_PIN_RESET);

                HAL_GPIO_WritePin(LED_RED_PORT, LED_RED_PIN, GPIO_PIN_RESET);

            }

            break;

        case SYS_STATE_INFLATING:

            // Yêu cầu: Đèn Vàng NHẤP NHÁY chậm, các đèn khác TẮT

            if (state_changed) {

                HAL_GPIO_WritePin(LED_GREEN_PORT, LED_GREEN_PIN, GPIO_PIN_RESET);

                HAL_GPIO_WritePin(LED_RED_PORT, LED_RED_PIN, GPIO_PIN_RESET);

            }

            // Logic nhấp nháy Non-blocking

            if (current_tick - previous_tick >= BLINK_NORMAL_MS) {

                previous_tick = current_tick;

                blink_flag = !blink_flag; // Đảo trạng thái (Sáng <-> Tắt)

                HAL_GPIO_WritePin(LED_YELLOW_PORT, LED_YELLOW_PIN, blink_flag ? GPIO_PIN_SET : GPIO_PIN_RESET);

            }

            break;

        case SYS_STATE_MEASURING:

            // Yêu cầu: Đèn Vàng SÁNG giữ nguyên, các đèn khác TẮT

            if (state_changed) {

                HAL_GPIO_WritePin(LED_GREEN_PORT, LED_GREEN_PIN, GPIO_PIN_RESET);

                HAL_GPIO_WritePin(LED_YELLOW_PORT, LED_YELLOW_PIN, GPIO_PIN_SET);

                HAL_GPIO_WritePin(LED_RED_PORT, LED_RED_PIN, GPIO_PIN_RESET);

            }

            break;

        case SYS_STATE_ERROR:

            // Yêu cầu: Đèn Đỏ SÁNG, báo lỗi (cần kiểm tra lại vòng bít/tay rung)

            if (state_changed) {

                HAL_GPIO_WritePin(LED_GREEN_PORT, LED_GREEN_PIN, GPIO_PIN_RESET);

                HAL_GPIO_WritePin(LED_YELLOW_PORT, LED_YELLOW_PIN, GPIO_PIN_RESET);

                HAL_GPIO_WritePin(LED_RED_PORT, LED_RED_PIN, GPIO_PIN_SET);

            }

            break;

        case SYS_STATE_EMERGENCY:

            // Yêu cầu: Đèn Đỏ NHẤP NHÁY NHANH, báo động dừng khẩn cấp

            if (state_changed) {

                HAL_GPIO_WritePin(LED_GREEN_PORT, LED_GREEN_PIN, GPIO_PIN_RESET);

                HAL_GPIO_WritePin(LED_YELLOW_PORT, LED_YELLOW_PIN, GPIO_PIN_RESET);

            }

            // Logic nhấp nháy Non-blocking (Tốc độ cao)

            if (current_tick - previous_tick >= BLINK_FAST_MS) {

                previous_tick = current_tick;

                blink_flag = !blink_flag; // Đảo trạng thái liên tục

                HAL_GPIO_WritePin(LED_RED_PORT, LED_RED_PIN, blink_flag ? GPIO_PIN_SET : GPIO_PIN_RESET);

            }

            break;

    }

}

```

### Hướng dẫn tích hợp vào chương trình chính

Trong hàm `main()` của bạn, cách thức hoạt động sẽ rất đơn giản và tách biệt. Khi một sự kiện xảy ra (như đọc nút nhấn), bạn chỉ việc thay đổi biến `current_sys_state`, hệ thống đèn sẽ tự động nhận biết và chạy đúng hiệu ứng!

```c

int main(void) {

    // 1. Gọi các hàm khởi tạo (HAL_Init, Cấu hình Clock, GPIO...)

    // Đảm bảo chân PB13, PB14, PB15 đã được set là GPIO Output trên CubeMX

    // Gán trạng thái khởi động mặc định

    current_sys_state = SYS_STATE_IDLE; 

    while (1) {

        // ------------- LUÔN GỌI HÀM LED NÀY ĐỂ ĐÈN CẬP NHẬT -------------

        LED_Update_Task(); 

        // ------------- VÍ DỤ VỀ CÁCH ĐỔI TRẠNG THÁI -------------

        // 1. Khi người dùng nhấn nút START (SW_START chân PB12)

        if (HAL_GPIO_ReadPin(GPIOB, GPIO_PIN_12) == GPIO_PIN_RESET) {

             current_sys_state = SYS_STATE_INFLATING; // Bật bơm, đèn vàng tự động nháy

             // Code bật GPIO cho Mosfet Bơm (Q201) chạy ở đây...

        }

        // 2. Khi người dùng nhấn khẩn cấp STOP (SW_STOP chân PB11)

        if (HAL_GPIO_ReadPin(GPIOB, GPIO_PIN_11) == GPIO_PIN_RESET) {

             current_sys_state = SYS_STATE_EMERGENCY; // Đèn đỏ tự động nháy liên tục

             // Code tắt Bơm, mở 100% Van (Q202) ở đây...

        }

        // Code đọc ADC và truyền UART nằm ở đây...

    }

}

```

**Ưu điểm của giải thuật này:**

1. Code cực nhẹ, chạy siêu tốc độ, **tôn trọng tuyệt đối thời gian thực** của máy đo huyết áp.

2. Kiểm tra `state_changed` giúp MCU không phải gọi hàm `HAL_GPIO_WritePin()` liên tục hàng nghìn lần mỗi giây, giúp tiết kiệm điện năng cho mạch.

3. Rất dễ mở rộng: Nếu sau này bạn thêm màn hình LCD hay còi Buzzer, bạn chỉ việc nhét thêm lệnh vào bên trong khối `if (state_changed)` là xong.

---

### Ánh xạ sang firmware (plan đo WebApp + UART)

Trong repo firmware, không dùng biến toàn cục `current_sys_state` như ví dụ trên; thay vào đó:

| `LedHmiSystemState_t` (LED_Algorithm) | Trạng thái máy (plan / `BpState`) |
|---|---|
| `LED_SYS_STATE_IDLE` | `STATE_IDLE`, và `STATE_DONE` (chờ về idle xanh) |
| `LED_SYS_STATE_INFLATING` | `STATE_INFLATE_SLOW_LISTEN` + `STATE_INFLATE_TO_MARGIN` |
| `LED_SYS_STATE_MEASURING` | `STATE_DEFLATE_MEASURE`; và `STATE_FAST_DEFLATE` **bình thường** sau xả |
| `LED_SYS_STATE_ERROR` | `STATE_ERROR` (hở khí / I2C…) |
| `LED_SYS_STATE_EMERGENCY` | `STATE_FAST_DEFLATE` khi **STOP**, **quá áp (≥ trần SAF hiệu lực)**, hoặc **ABORT** UART |

**API:** `LedHmiSystemState_t bp_fsm_led_hmi_state(void)` trong [`bp_fsm.c`](src/bp_fsm.c); hiển thị không chặn: `led_hmi_task(bp_fsm_led_hmi_state())` trong [`main.c`](src/main.c). Logic nhấp nháy nằm trong [`led_hmi.c`](src/led_hmi.c), chân LED theo schematic **PB13/PB14/PB15** trong [`board_config.h`](include/board_config.h).

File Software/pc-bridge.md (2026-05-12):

# PC / WebApp bridge — UART protocol

Firmware stream áp suất **100 Hz** trong mọi pha có đo (`INFLATE_SLOW_LISTEN`, `INFLATE_TO_MARGIN`, `DEFLATE_MEASURE`, …). WebApp (repo riêng) đọc cổng serial hoặc TCP bridge và xử lý tín hiệu.

## Thông số vật lý (đồng bộ plan)

- **Baud:** 115200, 8N1  
- **Tốc độ bơm chậm:** ~10 mmHg/s (`STATE_INFLATE_SLOW_LISTEN`) — servo PWM trên MCU  
- **SAF trần áp:** mặc định **175 mmHg** (`PRESSURE_SAFE_MAX_MMHG` trong `board_config.h`) — MCU tắt bơm, mở van, LED khẩn cấp khi áp ≥ trần hiệu lực.  
- **Lệnh target từ host:** clamp **≤** trần SAF hiệu lực (thường / HA — xem `SAF` / `SAFH` bên dưới).

### Đặt trần an toàn & chế độ HA (UART)

Giá trị clamp trong khoảng **120–300 mmHg** (giống firmware).

```
SAF,<mmHg>\r\n
SAFH,<mmHg>\r\n
HIGH,<0|1>\r\n
```

- **`SAF`:** trần thường (khi không ở chế độ HA).  
- **`SAFH`:** trần khi **HIGH** hiệu lực (nút phần cứng HIGH **hoặc** `HIGH,1` từ host).  
- **`HIGH,1` / `HIGH,0`:** bật/tắt chế độ huyết áp cao từ web (OR với nút HIGH trên board). Khi HA: fallback bơm +15 mmHg và dùng `SAFH` cho quá áp + clamp `T`.

Mặc định sau reset: `SAF` = `SAFH` = 175 mmHg (compile-time), có thể đổi lại bằng các lệnh trên.

## Khung TX (MCU → host)

### Stream mẫu (mỗi tick ~10 ms)

**Arduino / PlatformIO** (đầy đủ trường debug):

```
S,<seq>,<t_ms>,<p_mmHg>,<rc>,<counts>,<fsm>,<pump_pct>,<valve_pct>,<btn_s><btn_p><btn_h>\r\n
```

- `rc`: mã đọc ADS1115 (0 = OK).  
- `counts`: mẫu ADC (int16).  
- `fsm`: 0=IDLE 1=INFLATE_SLOW 2=INFLATE_MARGIN 3=DEFLATE 4=FAST_DEFLATE 5=DONE 6=ERROR.  
- `pump_pct` / `valve_pct`: PWM % (0–100).  
- `btn_s`, `btn_p`, `btn_h`: ba ký tự 0/1 — nút START / STOP / HIGH (đã đảo active-low).

**HAL CMake** (rút gọn): `S,<seq>,<t_ms>,<p_mmHg>\r\n` — WebApp chỉ cần 3 trường đầu sau `S,`.

- `seq`: số thứ tự mẫu tăng dần (uint32)  
- `t_ms`: thời gian ms trên MCU  
- `p_mmHg`: áp cuff (mmHg) sau chuyển đổi trên MCU

### Thông báo trạng thái / kết thúc

| Chuỗi | Ý nghĩa |
|---|---|
| `A,IDLE\r\n` | Sẵn sàng |
| `A,INFLATE_SLOW\r\n` | Đang bơm chậm + chờ WebApp “nghe” |
| `A,INFLATE_MARGIN\r\n` | Đang ramp tới target sau lệnh `T,...` |
| `A,DEFLATE\r\n` | Xả chậm đo oscillometric |
| `A,FAST_DEFLATE\r\n` | Xả nhanh (cuối chu kỳ hoặc an toàn) |
| `E,MEAS_END\r\n` | Kết thúc đo (áp đã xả thấp) |
| `E,SENSOR_OR_LEAK\r\n` | Lỗi cảm biến / hở khí (timeout tăng áp) |

## Khung RX (host → MCU)

Kết thúc dòng bằng `\n` (CR có thể bị bỏ qua).

### Đặt mục tiêu áp cuff (sau khi WebApp ước lượng SYS)

```
T,<target_mmHg>\r\n
```

Ví dụ WebApp tính `P_sys_est + 40` → gửi `T,165` (sẽ bị clamp nếu > 175).

### Hủy / dừng đo từ host

```
ABORT\r\n
```

hoặc rút gọn:

```
A\r\n
```

Tương đương yêu cầu xả nhanh an toàn (giống STOP phần cứng về hành vi xả).

### Tốc độ xả chậm (Arduino PIO / WebApp)

```
DR,<mmHg/s>\r\n
EARLYEND\r\n
```

- **`DR`:** setpoint tốc độ giảm áp trong pha xả đo (clamp firmware, thường 0.8–4 mmHg/s).  
- **`EARLYEND`:** yêu cầu kết thúc xả chậm sớm khi đang đo (theo điều kiện firmware).

### Bắt đầu đo từ WebApp (lệnh `START`)

Khi FSM đang **IDLE** (hoặc vừa về IDLE sau đo), MCU **chỉ** vào pha bơm chậm nếu có **nút START phần cứng** hoặc lệnh:

```
START\r\n
```

(hoa thường tùy ý). Hành vi tương đương một lần nhấn START trên board. Sau đó host gửi `T,...` trong pha `INFLATE_SLOW` như luồng oscillometric.

### Xác nhận đã parse lệnh (MCU → host)

Sau khi parse thành công một lệnh RX hợp lệ, firmware gửi một dòng ngắn (ASCII):

```
R,OK,<từ_khóa>\r\n
```

Ví dụ: `R,OK,START`, `R,OK,T`, `R,OK,SAF`, `R,OK,SAFH`, `R,OK,HIGH`, `R,OK,DR`, `R,OK,ABORT`. WebApp có thể hiển thị để biết MCU đã nhận dòng lệnh (khác với `A,...` là thông báo **trạng thái FSM**).

**Lưu ý HAL CMake:** xác nhận `R,...` được đưa vào hàng đợi trong ngắt RX và gửi từ vòng `main` (không gọi `HAL_UART_Transmit` trực tiếp trong ISR).

## Luồng WebApp (đề xuất)

1. **Band-pass 0.5–5 Hz** trên chuỗi áp (hoặc high-pass quanh đường bao chậm).  
2. Gửi `START` (hoặc bấm START trên board) để vào pha bơm chậm.  
3. Trong pha bơm chậm, phát hiện **dao động đầu tiên** đủ biên độ → ghi **`P_sys_est`** (đồng bộ `t_ms` / `seq`).  
4. Gửi `T,<P_sys_est + margin>\r\n` (margin mặc định firmware/WebApp ~40 mmHg), clamp theo SAF hiệu lực.  
5. **Tùy chọn — cắt sớm (host):** nếu áp cuff ≥ ngưỡng cấu hình và `|AC|` yên đủ lâu trong pha bơm, WebApp có thể gửi `T,...` sớm hơn mà không cần chạm trần SAF.  
6. Trong pha xả, chạy **MAA / envelope** để MAP, SBP/DBP (theo [`algorithm.md`](../algorithm.md)).

## LED (tóm tắt UX phần cứng)

| Trạng thái | Đèn |
|---|-----|
| Idle / Done | Xanh sáng |
| Inflate (slow + margin) | Vàng nhấp nháy ~500 ms |
| Đo / xả bình thường | Vàng sáng |
| STOP / ≥175 / ABORT → fast deflate | Đỏ nhấp nháy ~150 ms |
| Error (leak / I2C) | Đỏ sáng |

Chi tiết: [`LED_Algorithm.md`](../LED_Algorithm.md).

## Fallback không có WebApp

Firmware sau timeout có thể chuyển sang ramp fallback (`INFLATE_FALLBACK_TARGET_MMHG` trong `board_config.h`). SAF **175 mmHg** và STOP **luôn** áp dụng.

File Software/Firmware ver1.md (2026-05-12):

### 1. KIẾN TRÚC FÍRMWARE (Firmware Architecture)

Do vi điều khiển phải làm nhiều việc cùng lúc (đọc I2C, lọc nhiễu, tính toán, gửi UART, điều khiển bơm/van), bạn bắt buộc phải thiết kế code theo dạng **Máy trạng thái (State Machine)** kết hợp với **Ngắt Timer (Timer Interrupt)**.

**Các trạng thái (States) chính của hệ thống:**

1. `STATE_IDLE`: Chờ lệnh bắt đầu từ nút nhấn hoặc từ WebApp.

2. `STATE_INFLATE`: Bật bơm (PWM = 100%), đóng van. Bơm vòng bít lên ngưỡng ~160 - 180 mmHg.

3. `STATE_DEFLATE_MEASURE`: Tắt bơm, mở van từ từ (PWM ~30-40%) để xả khí chậm (tốc độ lý tưởng là giảm 3-5 mmHg/giây). Bắt đầu thu thập và xử lý tín hiệu AC/DC tại đây.

4. `STATE_CALCULATE`: Xả nhanh toàn bộ khí (Mở van 100%). Chạy thuật toán tìm MAP, SYS (Tâm thu), DIA (Tâm trương).

5. `STATE_SEND_RESULT`: Gửi kết quả cuối cùng qua UART và quay về `IDLE`.

---

### 2. THUẬT TOÁN TÁCH TÍN HIỆU (AC/DC Separation) TRÊN STM32

STM32F103 (Core M3) **không có bộ xử lý số thực phần cứng (No Hardware FPU)**, nên các phép toán `float` sẽ chạy bằng phần mềm hơi chậm một chút. Tuy nhiên, với tần số lấy mẫu chậm (100Hz = 10ms/lần), STM32F103 hoàn toàn dư sức gánh vác.

Để tiết kiệm tài nguyên CPU, ta không dùng các bộ lọc bậc cao phức tạp, mà dùng **Bộ lọc trung bình trượt theo hàm mũ (Exponential Moving Average - EMA Filter)** hoặc IIR bậc 1.

**Công thức C cốt lõi đặt trong ngắt Timer 10ms (100Hz):**

```c

// Các biến toàn cục

float raw_pressure = 0.0;

float dc_pressure = 0.0;   // Áp suất vòng bít (DC)

float ac_pulse = 0.0;      // Dao động nhịp tim (AC)

// Trọng số cho bộ lọc thông thấp (Low-pass filter) - Điều chỉnh từ 0.01 đến 0.1

#define ALPHA_DC 0.05 

void HAL_TIM_PeriodElapsedCallback(TIM_HandleTypeDef *htim) {

    if (htim->Instance == TIM2) { // Ngắt chu kỳ 10ms

        if(current_state == STATE_DEFLATE_MEASURE) {

            // 1. Đọc giá trị thô từ ADS1115 (qua I2C)

            int16_t adc_raw = ADS1115_Read();

            // Chuyển đổi ADC sang mmHg (Cần hệ số calib thực tế của MPX5050GP)

            raw_pressure = (adc_raw - OFFSET) * SCALE_FACTOR; 

            // 2. Tách tín hiệu DC (Áp suất tĩnh của vòng bít) bằng Low-Pass Filter

            dc_pressure = (ALPHA_DC  *raw_pressure) + ((1.0 - ALPHA_DC)*  dc_pressure);

            // 3. Tách tín hiệu AC (Dao động mạch máu)

            // Tín hiệu AC chính là Tín hiệu thô trừ đi tín hiệu gốc DC

            ac_pulse = raw_pressure - dc_pressure;

            // (Tùy chọn) Đưa ac_pulse qua một bộ lọc Bandpass/Moving Average nhẹ nữa để cho mượt đồ thị

            // 4. Bắn dữ liệu THỜI GIAN THỰC qua UART lên WebApp để vẽ đồ thị

            Send_Realtime_UART(dc_pressure, ac_pulse);

            // 5. Lưu vào mảng để thuật toán tính Huyết áp xử lý

            Process_Oscillometric_Data(dc_pressure, ac_pulse);

        }

    }

}

```

---

### 3. THUẬT TOÁN TÍNH HUYẾT ÁP (The Oscillometric Algorithm)

Lưu ý quan trọng: RAM của STM32F103C8T6 chỉ có **20KB**. Nếu quá trình xả khí mất 30 giây ở 100Hz, bạn sẽ có 3000 mẫu dữ liệu. Không thể lưu tất cả vào RAM. **Bạn chỉ được phép lưu các "ĐỈNH" (Peaks) của tín hiệu AC.**

**Cách làm (Bên trong hàm `Process_Oscillometric_Data`):**

1. **Tìm đỉnh (Peak Detection):** Liên tục theo dõi biến `ac_pulse`. Nếu thấy tín hiệu đi lên rồi đi xuống, đó là 1 nhịp tim (1 đỉnh).

2. **Lưu đỉnh:** Ghi lại **Biên độ của đỉnh AC đó (Amplitude)** và **Giá trị DC tương ứng** tại thời điểm đó vào 2 mảng nhỏ (khoảng 50-80 phần tử là đủ cho 1 lần đo).

3. **Tính toán (Khi chuyển sang `STATE_CALCULATE`):**

    *Tìm đỉnh AC có biên độ lớn nhất trong mảng $\rightarrow$ Đó chính là* *MAP (Mean Arterial Pressure - Huyết áp trung bình)**.

   * **Huyết áp tâm thu (SYS):** Tìm ngược từ vị trí MAP về phía đầu mảng, tìm điểm có biên độ AC xấp xỉ bằng `0.55 * Max_AC`. Lấy áp suất DC tại điểm đó làm Tâm Thu.

   * **Huyết áp tâm trương (DIA):** Tìm xuôi từ vị trí MAP về phía cuối mảng, tìm điểm có biên độ AC xấp xỉ bằng `0.85 * Max_AC`. Lấy áp suất DC tại điểm đó làm Tâm Trương.

   * *(Lưu ý: Hệ số 0.55 và 0.85 là hệ số thực nghiệm tiêu chuẩn, bạn có thể phải tinh chỉnh lại lúc test thực tế).*

---

### 4. GIAO THỨC TRUYỀN DỮ LIỆU QUA UART (UART Protocol Formulation)

Để WebApp có thể phân biệt được đâu là dữ liệu đang vẽ đồ thị, đâu là kết quả cuối cùng, bạn cần quy định một Format truyền chuỗi (String Protocol) đơn giản.

*Khuyến nghị set Baudrate UART: 115200 bps.*

**A. Khung truyền Real-time (Gửi mỗi 10ms để vẽ đồ thị):**

Sử dụng format chữ cái đầu làm cờ báo.

*Format:* `D,<DC_Value>,<AC_Value>\n`

*Ví dụ STM32 gửi:*

```text

D,140.5,0.12

D,140.2,0.45

D,139.8,1.20   <- Đang có mạch đập

```

**B. Khung truyền Kết quả (Chỉ gửi 1 lần khi đo xong):**

*Format:* `R,<SYS>,<DIA>,<HR>\n` (HR là Heart Rate - Nhịp tim)

*Ví dụ STM32 gửi:*

```text

R,120,80,75

```

**Code C mô phỏng khối gửi UART:**

```c

char uart_buf[50];

// Hàm gửi lúc đang đo

void Send_Realtime_UART(float dc, float ac) {

    // Dùng sprintf để format chuỗi

    sprintf(uart_buf, "D,%.1f,%.2f\n", dc, ac);

    HAL_UART_Transmit(&huart1, (uint8_t*)uart_buf, strlen(uart_buf), 10);

}

// Hàm gửi lúc đo xong

void Send_Result_UART(int sys, int dia, int hr) {

    sprintf(uart_buf, "R,%d,%d,%d\n", sys, dia, hr);

    HAL_UART_Transmit(&huart1, (uint8_t*)uart_buf, strlen(uart_buf), 100);

}

```

---

### TÓM LẠI: Ưu/Nhược điểm của phương pháp này

**Ưu điểm:**

*   **Bảo mật & Đóng gói:** Thuật toán (chất xám của bạn) nằm toàn bộ trên MCU, không bị lộ code trên trình duyệt.

*   **Đúng chuẩn Y tế:** Nếu WebApp bị treo, trình duyệt bị crash, dây cáp lỏng... Máy đo vẫn tự động hoạt động, tự động xả van an toàn vì não bộ điều khiển (STM32) làm chủ hoàn toàn quá trình cơ học.

*   **WebApp nhẹ nhàng:** WebApp lúc này chỉ cần đọc chuỗi Text từ Serial, tách dấu phẩy `,`) và push vào Chart. Cực kỳ nhẹ, mượt và dễ lập trình.

**Nhược điểm (Thách thức cho người code):**

*   Bạn phải có kỹ năng code C/C++ khá tốt, đặc biệt là kiểm soát bộ nhớ RAM khi thao tác mảng.

*   Phải tự viết thuật toán tìm đỉnh (Peak Detection) trên C.

*   Khó Debug thuật toán hơn so với Web: Khi thuật toán tính sai, bạn phải in các mảng dữ liệu ra console để xem tại sao nó bắt nhầm đỉnh, thay vì dùng các công cụ debug trực quan như trên web.

*Gợi ý:* Trong giai đoạn đầu, bạn cứ in TOÀN BỘ dữ liệu thô `[Thời gian, Giá trị ADC]` ra Serial Monitor, copy vào Excel để vẽ biểu đồ và tìm hệ số lọc (Alpha) cũng như hệ số biên độ (0.55/0.85) chuẩn xác nhất cho cảm biến của mình, sau đó mới viết thuật toán nhúng hẳn vào STM32.

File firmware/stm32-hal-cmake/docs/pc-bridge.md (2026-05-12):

# PC / WebApp bridge — UART protocol

Firmware stream áp suất **100 Hz** trong mọi pha có đo (`INFLATE_SLOW_LISTEN`, `INFLATE_TO_MARGIN`, `DEFLATE_MEASURE`, …). WebApp (repo riêng) đọc cổng serial hoặc TCP bridge và xử lý tín hiệu.

## Thông số vật lý (đồng bộ plan)

- **Baud:** 115200, 8N1  
- **Tốc độ bơm chậm:** ~10 mmHg/s (`STATE_INFLATE_SLOW_LISTEN`) — servo PWM trên MCU  
- **SAF trần áp:** mặc định **175 mmHg** — MCU tắt bơm, mở van, LED khẩn cấp khi áp ≥ trần hiệu lực.  
- **Lệnh target từ host:** clamp **≤** trần SAF hiệu lực (xem `SAF` / `SAFH`).

### Đặt trần an toàn & chế độ HA (UART)

Giá trị clamp **120–300 mmHg** (giống firmware).

```
SAF,<mmHg>\r\n
SAFH,<mmHg>\r\n
HIGH,<0|1>\r\n
```

- **`SAF`:** trần thường. **`SAFH`:** trần khi HIGH (nút hoặc `HIGH,1`). **`HIGH`:** bật/tắt HA từ host.

## Khung TX (MCU → host)

### Stream mẫu (mỗi tick ~10 ms) — bản HAL

```
S,<seq>,<t_ms>,<p_mmHg>\r\n
```

Bản **Arduino / PlatformIO** trong repo có thêm trường debug sau `p_mmHg`; WebApp chỉ cần ba trường đầu.

- `seq`: số thứ tự mẫu tăng dần (uint32)  
- `t_ms`: `HAL_GetTick()`  
- `p_mmHg`: áp cuff (mmHg) trên MCU

### Thông báo trạng thái / kết thúc

| Chuỗi | Ý nghĩa |
| --- | --- |
| `A,IDLE\r\n` | Sẵn sàng |
| `A,INFLATE_SLOW\r\n` | Đang bơm chậm + chờ WebApp “nghe” |
| `A,INFLATE_MARGIN\r\n` | Đang ramp tới target sau lệnh `T,...` |
| `A,DEFLATE\r\n` | Xả chậm đo oscillometric |
| `A,FAST_DEFLATE\r\n` | Xả nhanh (cuối chu kỳ hoặc an toàn) |
| `E,MEAS_END\r\n` | Kết thúc đo (áp đã xả thấp) |
| `E,SENSOR_OR_LEAK\r\n` | Lỗi cảm biến / hở khí (timeout tăng áp) |

## Khung RX (host → MCU)

Kết thúc dòng bằng `\n` (CR có thể bị bỏ qua).

### Đặt mục tiêu áp cuff (sau khi WebApp ước lượng SYS)

```
T,<target_mmHg>\r\n
```

Ví dụ WebApp tính `P_sys_est + 40` → gửi `T,165` (sẽ bị clamp nếu > 175).

### Hủy / dừng đo từ host

```
ABORT\r\n
```

hoặc rút gọn:

```
A\r\n
```

Tương đương yêu cầu xả nhanh an toàn (giống STOP phần cứng về hành vi xả).

### Tốc độ xả chậm khi đo (Arduino PIO / WebApp)

```
DR,<mmHg_per_s>\r\n
```

- Clamp trên firmware: **0.8–4.0** mmHg/s (mặc định nội bộ 1.8 nếu chưa nhận `DR`).
- Áp dụng trong `DEFLATE_MEASURE`. Mỗi lần **bắt đầu đo mới** (START từ IDLE), MCU reset về tốc độ mặc định; WebApp gửi lại `DR` ở mẫu đầu pha xả.

### Kết thúc xả chậm sớm (đủ bao oscillometric)

```
EARLYEND\r\n
```

- Chỉ có hiệu lực khi đang **`DEFLATE_MEASURE`**. MCU chuyển **xả nhanh** tới áp thấp rồi `DONE` / `E,MEAS_END` như bình thường.
- LED: không dùng nhấp nháy đỏ khẩn cấp (khác STOP).
- WebApp có thể gửi khi đã thu đủ đường bao và áp cuff đủ thấp (logic host — xem WebApp).

## Luồng WebApp (đề xuất)

1. **Band-pass 0.5–5 Hz** trên chuỗi áp (hoặc high-pass quanh đường bao chậm).
2. Trong pha bơm chậm, phát hiện **dao động đầu tiên** đủ biên độ → ghi `**P_sys_est`** (đồng bộ `t_ms` / `seq`).
3. Gửi `T,<P_sys_est + margin>\r\n`, clamp theo SAF hiệu lực.  
4. **Tùy chọn (host):** cắt sớm khi áp đủ cao và `|AC|` yên — gửi `T,...` sớm.  
5. Trong pha xả, chạy **MAA / envelope** để MAP, SBP/DBP (theo `[algorithm.md](../algorithm.md)`).

## LED (tóm tắt UX phần cứng)

| Trạng thái | Đèn |
| --- | --- |
| Idle / Done | Xanh sáng |
| Inflate (slow + margin) | Vàng nhấp nháy ~500 ms |
| Đo / xả bình thường | Vàng sáng |
| STOP / ≥175 / ABORT → fast deflate | Đỏ nhấp nháy ~150 ms |
| `EARLYEND` → fast deflate (cuối đo) | Vàng sáng (vẫn đo) |
| Error (leak / I2C) | Đỏ sáng |

Chi tiết: `[LED_Algorithm.md](../LED_Algorithm.md)`.

## Fallback không có WebApp

Firmware sau timeout có thể chuyển sang ramp fallback (`INFLATE_FALLBACK_TARGET_MMHG` trong `board_config.h`). SAF **175 mmHg** và STOP **luôn** áp dụng.

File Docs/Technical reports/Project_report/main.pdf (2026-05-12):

ĐẠI HỌC QUỐC GIA THÀNH PHỐ HỒ CHÍ MINH TRƯỜNG ĐẠI HỌC BÁCH KHOA THÀNH PHỐ HỒ CHÍ MINH KHOA ĐIỆN - ĐIỆN TỬ
BỘ MÔN VIỄN THÔNG
——————– * ———————

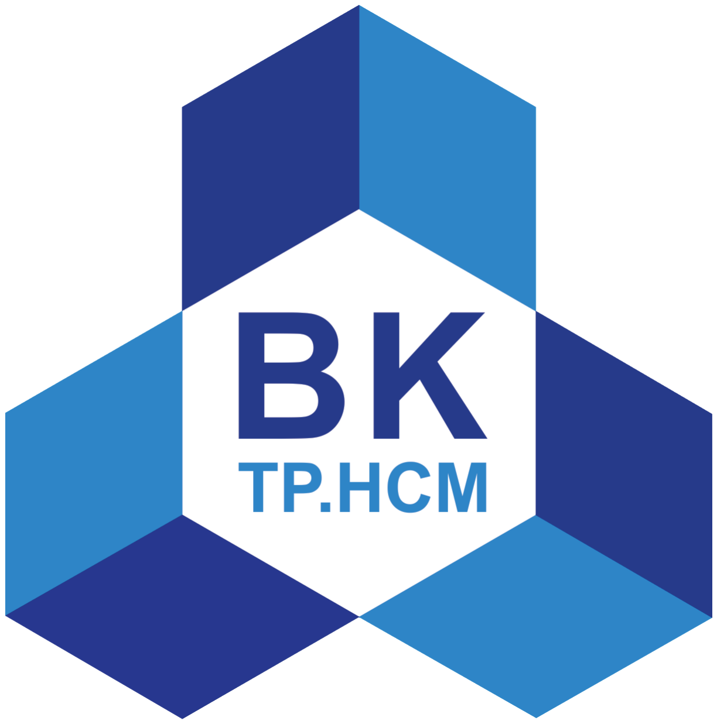
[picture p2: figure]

BÁO CÁO ĐỒ ÁN — EE3037

# THIẾT KẾ MÁY ĐO HUYẾT ÁP OSCILLOMETRIC DỰA TRÊN MPX5050 VÀ STM32F103

GVHD: (Điền họ tên giảng viên hướng dẫn) SVTH: Phan Trần Thế Huy
MSSV: (Điền MSSV)

Thành phố Hồ Chí Minh, tháng 5 năm 2026

## LỜI CẢM ƠN

Em xin gửi lời cảm ơn chân thành đến thầy (Điền họ tên giảng viên hướng dẫn) đã nhiệt tình giúp đỡ và chỉ dẫn em trong suốt quá trình thực hiện đề tài. Nhờ sự hướng dẫn tận tình và những góp ý quý báu của thầy mà em đã hoàn thành tốt được đồ án. Em xin gửi lời cảm ơn đến quý thầy cô đã dạy dỗ và cung cấp kiến thức có liên quan để em có thể thực hiện được đề tài này một cách hiệu quả. Mặc dù vậy, trong quá trình thực hiện đề tài khó tránh khỏi sai sót, mong thầy cô đánh giá và nhận xét để em có thể hoàn thành những đề tài sau được tốt hơn. Em xin chân thành cảm ơn!

TP. Hồ Chí Minh, tháng 5 năm 2026 Sinh viên

Phan Trần Thế Huy

## TÓM TẮT ĐỀ TÀI

Đề tài trình bày thiết kế một máy đo huyết áp điện tử theo phương pháp oscillometric: áp suất trong băng được đo bằng cảm biến áp tuyến tính NXP MPX5050, chuyển đổi tương tự–số qua ADC ngoài Texas Instruments ADS1115 giao tiếp I²C với vi điều khiển STM32F103 (Blue Pill). Firmware điều khiển bơm và van bằng PWM để bơm chậm, ramp đến mục tiêu và xả chậm trong khi đo; đồng thời truyền dòng dữ liệu áp suất khoảng 100 mẫu/giây qua UART (115200 bps) về máy tính.
Phần mềm host (WebApp Vite + TypeScript, Web Serial trên Chrome/Edge) lọc số dải thông 0,5–5 Hz, ước lượng áp tâm thu đại diện trong pha bơm chậm để gửi lệnh đặt áp mục tiêu T,<mmHg> xuống MCU; trong pha xả, máy chủ tạo đường bao dao động và áp dụng thuật toán biên độ cực đại (MAA) với các hệ số đặc trưng rs, rd để suy ra MAP, SBP và DBP. Hệ thống có cơ chế an toàn cục bộ: trần áp 280 mmHg, dừng khẩn cấp nút cứng và lệnh ABORT, báo hiệu LED (đỏ/vàng/xanh) theo trạng thái đo.
Kết quả là một nguyên mẫu phần cứng–phần mềm thống nhất phục vụ đo và hiển thị trên trình duyệt; độ chính xác lâm sàng phụ thuộc hiệu chỉnh cảm biến và tinh chỉnh tham số MAA, được nêu trong kết luận và hướng phát triển.

## MỤC LỤC

1 GIỚI THIỆU | 1
2 CƠ SỞ PHẦN CỨNG | 3
3 FIRMWARE VÀ THUẬT TOÁN OSCILLOMETRIC | 5
4 PHẦN MỀM HOST VÀ KIỂM THỬ | 7
Kết luận | 10

III

## DANH MỤC ẢNH MINH HỌA

2.1 Bản in schematic/board (trích từ dự án KiCad OscilloBP Monitor) | 4
4.1 Minh họa giao diện WebApp (ảnh hero trong kho mã) | 8

IV

## DANH MỤC BẢNG

3.1 Các dòng lệnh/thông báo UART tiêu biểu | 5

V

## DANH MỤC CHỮ VIẾT TẮT

ADC Analog-to-Digital Converter (bộ chuyển đổi tương tự–số) ADS1115 Bộ ADC Sigma-Delta 16-bit (Texas Instruments)
DBP | Diastolic Blood Pressure (huyết áp tâm trương)
FSM | Finite State Machine (máy trạng thái hữu hạn)
HMI | Human–Machine Interface (giao diện người–máy)
I
2C | Giao tiếp nối tiếp hai dây
MAA | Maximum Amplitude Algorithm (thuật toán biên độ cực đại)
MAP | Mean Arterial Pressure (huyết áp trung bình động mạch)
MCU | Microcontroller Unit (vi điều khiển)
MPX5050 Cảm biến áp tích hợp (NXP)
OWE | Oscillometric Waveform Envelope (đường bao dao động oscillometric)
PWM | Pulse Width Modulation (điều chế độ rộng xung)
SAF | Safety (an toàn – giới hạn áp cực đại)
SBP | Systolic Blood Pressure (huyết áp tâm thu)
UART | Universal Asynchronous Receiver/Transmitter

VI

BÁO CÁO ĐỒ ÁN — EE3037 | Chương 1. GIỚI THIỆU

# Chương 1 GIỚI THIỆU

## 1.1 Tổng quan đề tài

Đo huyết áp động mạch là một trong các chỉ số sinh lý quan trọng trong chẩn đoán và theo dõi bệnh tim mạch. Trong thực hành lâm sàng cổ điển, phương pháp Korotkoff kết hợp máy đo thủy ngân và ống nghe cho phép xác định áp tâm thu (SBP) và áp tâm trương (DBP) nhờ âm thanh nghe được khi xả khí vòng bít. Máy đo điện tử hiện đại phổ biến thay thế tai nghe bằng việc phân tích dao động áp suất nhỏ trên nền áp suất bao (oscillometric), phù hợp với phần cứng chi phí thấp và tái lập trình.
Đề tài xây dựng một nguyên mẫu máy đo oscillometric với các đặc điểm sau:
- Cảm biến áp: MPX5050GP (đầu ra tương tự thuận tiện khuếch đại/đọc ADC).
- Bộ chuyển đổi số: ADS1115 độ phân giải 16-bit, giao tiếp I²C với STM32F103.
- Điều khiển khí nén: bơm và van được điều chỉnh bằng PWM để đạt tốc độ bơm và xả mong muốn.
- An toàn: giới hạn áp suất cực đại 280 mmHg (SAF), dừng khẩn cấp nút cứng và lệnh serial ABORT.
- Host: WebApp đọc cổng serial (Web Serial), hiển thị sóng áp và thực hiện lọc số + thuật toán MAA để suy ra MAP, SBP, DBP.

## 1.2 Nhiệm vụ đề tài

Nội dung 1: Phần cứng và bo mạch (OscilloBP Monitor).
- Mục tiêu: Hoàn thiện mạch đo áp, MCU, điều khiển bơm/van, nút nhấn và LED trạng thái theo schematic/PCB trong kho mã.
- Ý tưởng thực hiện: MPX5050 cấp điện áp tỉ lệ áp suất; ADS1115 lấy mẫu ổn định hơn ADC nội Blue Pill; STM32 điều phối FSM đo và streaming UART.
Nội dung 2: Firmware STM32 (PlatformIO / STM32Cube).
- Mục tiêu: Đọc áp liên tục trong các pha đo, điều khiển bơm/van theo tốc độ đặt trước, đồng bộ với lệnh T,... từ host.
- Ý tưởng thực hiện: Máy trạng thái gồm các pha bơm chậm (nghe dao động), ramp margin, xả chậm đo, xả nhanh kết thúc hoặc an toàn; định dạng khung S,<seq>,<t_ms>,<p_mmHg> và thông báo A,..., E,....
Nội dung 3: Phần mềm host và kiểm chứng.

BÁO CÁO ĐỒ ÁN — EE3037 | Chương 1. GIỚI THIỆU
- Mục tiêu: Hiển thị thời gian thực, lọc dao động, tính MAP/SBP/DBP bằng MAA; kiểm thử UART, LED và SAF.
- Ý tưởng thực hiện: Band-pass 0,5–5 Hz trên chuỗi áp; phát hiện dao động đầu tiên trong pha bơm chậm để ước lượng P_sys_est và gửi T,P_sys_est+margin.

## 1.3 Bố cục báo cáo

Ngoài phần đầu (tóm tắt, mục lục, danh mục hình/bảng và viết tắt), báo cáo gồm bốn chương chính và phần kết luận. Chương 2 trình bày kiến trúc phần cứng và hình ảnh schematic/in PCB. Chương 3 mô tả firmware, giao thức serial và cơ sở thuật toán oscillometric/MAA được triển khai trên host. Chương 4 giới thiệu WebApp và checklist kiểm thử. Kết luận tóm tắt kết quả, hạn chế và hướng phát triển.

BÁO CÁO ĐỒ ÁN — EE3037 | Chương 2. CƠ SỞ PHẦN CỨNG

# Chương 2 CƠ SỞ PHẦN CỨNG

## 2.1 Sơ đồ khối chức năng

Hệ thống gồm các khối sau:
1. Vòng bít và đường khí nối: chứa áp suất làm xẹp động mạch và truyền áp tới cảm biến.
2. Cảm biến MPX5050: chuyển áp suất tương đối thành điện áp tương tự (khảo sát đường đặc tuyến trong datasheet).
3. ADC ADS1115: chuyển đổi điện áp với độ phân giải 16-bit; giao tiếp I²C với MCU (địa chỉ thiết bị mặc định 0x48 khi chân ADDR nối GND).
4. Vi điều khiển STM32F103 (Blue Pill): đọc ADS1115, điều khiển PWM bơm và van, đọc nút nhấn, điều khiển LED và truyền thông UART.
5. Nguồn và điều kiện tiếp đất: đảm bảo MPX5050 và ADC có tham chiếu ổn định; layout PCB tuân thủ khuyến nghị của nhà sản xuất để giảm nhiễu đo lường.

## 2.2 Giao tiếp và chân cắm chính

Theo cấu hình mặc định trong firmware (board_config.h):
- UART1 115200 bps: PA9 (TX), PA10 (RX).
- I2C1: PB6 (SCL), PB7 (SDA) nối ADS1115.
- Timer 3 PWM: PA6 kênh bơm, PA7 kênh van (điều chỉnh duty để servo tốc độ bơm/xả).
- Nút tác động mức thấp (kéo lên nội bộ): PA3 Start, PA4 Stop, PA5 High-mode.
- LED báo hiệu: PB13 đỏ, PB14 xanh, PB15 vàng (ánh xạ trạng thái đo và cảnh báo).

## 2.3 An toàn và giới hạn vật lý

- Trần áp 280 mmHg: firmware ngắt bơm và mở van để xả nhanh khi vượt ngưỡng hoặc khi người dùng nhấn Stop/ABORT.
- Timeout rò khí: nếu áp không tăng đủ trong khoảng thời gian đặt (ví dụ rò đường khí), FSM báo lỗi cảm biến/rò và chuyển LED đỏ báo lỗi.

BÁO CÁO ĐỒ ÁN — EE3037 | Chương 2. CƠ SỞ PHẦN CỨNG

## 2.4 Schematic và PCB

Thiết kế schematic và bản vẽ PCB được hoàn thiện trong dự án KiCad OscilloBP Monitor. Hình 2.1 trích bản in PDF trong kho mã (có thể thay bằng ảnh độ phân giải cao hơn khi cần in báo cáo).

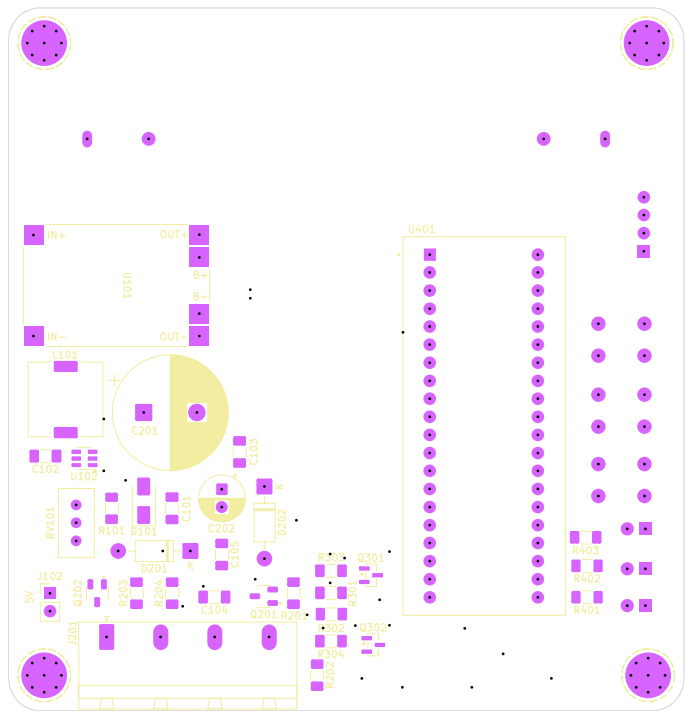
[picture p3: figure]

Figure 2.1: Bản in schematic/board (trích từ dự án KiCad OscilloBP Monitor).

## 2.5 Nhiệm vụ hiệu chỉnh phần cứng

Để đọc mmHg chính xác từ ADC, cần hiệu chỉnh hai tham số trong firmware: PRESSURE_ADC_OFFSET_COUNTS và PRESSURE_ADC_SCALE_MMHG_PER_COUNT so với đồng hồ áp chuẩn hoặc nguồn áp đã biết.
Đây là bước bắt buộc trước khi đánh giá lâm sàng.

BÁO CÁO ĐỒ ÁN — EE3037Chương 3. FIRMWARE VÀ THUẬT TOÁN OSCILLOMETRIC

# Chương 3 FIRMWARE VÀ THUẬT TOÁN OSCILLOMETRIC

## 3.1 Kiến trúc phần mềm nhúng

Firmware được xây dựng bằng PlatformIO, board bluepill_f103c8, framework STM32Cube HAL. Các module chính:
- Driver ADS1115 đọc kênh vi sai phù hợp với điện áp ra của MPX5050 và PGA đặt trong phạm vi đầy thang không bão hòa.
- Chuyển đổi đếm ADC → áp suất cuff (mmHg) bằng offset và hệ số scale (hiệu chỉnh thực nghiệm).
- FSM đo huyết áp: pha bơm chậm có “nghe” dao động; pha ramp đến mục tiêu sau lệnh host; pha xả chậm để thu sóng oscillometric; pha xả nhanh kết thúc hoặc an toàn.
- UART text-line: stream mẫu và thông báo trạng thái cho WebApp.

## 3.2 Luồng đo và giao thức UART

Bảng 3.1 tóm tắt các khung điển hình (chi tiết trong tài liệu pc-bridge.md của kho mã).
Table 3.1: Các dòng lệnh/thông báo UART tiêu biểu.
Dòng | Ý nghĩa
S,<seq>,<t_ms>,<p_mmHg> | Stream áp suất ( 100 Hz trong đo)
A,IDLE / A,INFLATE_SLOW / A,DEFLATE Trạng thái FSM
T,<target_mmHg> | Host đặt áp mục tiêu (clamp ≤ SAF)
ABORT hoặc A | Yêu cầu xả nhanh an toàn
E,MEAS_END | Kết thúc đo

Tốc độ nền: baud 115200, kết thúc dòng \r\n. Trần SAF 280 mmHg áp dụng đồng nhất cho điều khiển cục bộ và clamp lệnh T,....

BÁO CÁO ĐỒ ÁN — EE3037Chương 3. FIRMWARE VÀ THUẬT TOÁN OSCILLOMETRIC

## 3.3 Cơ sở thuật toán MAA trên host

Thuật toán biên độ cực đại (MAA) làm việc trên đường bao dao động (OWE) của thành phần AC của áp suất cuff trong quá trình xả chậm:
1. Xác định MAP là áp suất cuff tại điểm biên độ dao động cực đại Amax.
2. Với các hệ số đặc trưng rs (tâm thu) và rd (tâm trương), tính các mức biên độ mục
tiêu Asys = rsAmax, Adia = rdAmax.
3. Dò nhánh áp cao hơn MAP để tìm điểm gần Asys ⇒ SBP; dò nhánh áp thấp hơn MAP để tìm điểm gần Adia ⇒ DBP.
Trên host, trước khi trích envelope và cực đại, tài liệu kỹ thuật dự án khuyến nghị lọc số dải thông 0,5–5 Hz để giữ nhịp mạch và giảm nhiễu tay/run.

## 3.4 Đồng bộ với pha bơm chậm

Trong pha INFLATE_SLOW, WebApp theo dõi dao động sau lọc để ước lượng P_sys_est. Sau đó host gửi T, P_sys_est + 40 (margin mặc định trong board_config.h) để MCU ramp đến mục tiêu rồi chuyển xả chậm đo. Nếu không có host trong thời gian chờ, firmware có thể ramp theo mục tiêu dự phòng (INFLATE_FALLBACK_TARGET_MMHG).

## 3.5 LED và trải nghiệm người dùng

LED phản ánh trạng thái không chặn luồng đo (tham chiếu LED_Algorithm.md): idle/done xanh; bơm margin vàng nhấp nháy; đo/xả vàng sáng; STOP/SAF/ABORT đỏ nhấp nháy nhanh; lỗi rò/I2C đỏ sáng.

BÁO CÁO ĐỒ ÁN — EE3037 Chương 4. PHẦN MỀM HOST VÀ KIỂM THỬ

# Chương 4 PHẦN MỀM HOST VÀ KIỂM THỬ

## 4.1 WebApp và Web Serial

Ứng dụng web (Software/webapp) dùng Vite và TypeScript, chạy trên trình duyệt Chrome hoặc Edge với API Web Serial để mở cổng USB–TTL nối UART của MCU. Giao diện hiển thị sóng áp thời gian thực và các nút điều khiển (Hủy gửi ABORT; ô kiểm SAF có thể minh họa clamp khi gửi T,300).

## 4.2 Xử lý tín hiệu trên host

Luồng xử lý khuyến nghị:
1. Thu thập chuỗi mẫu áp từ các dòng S,....
2. Áp dụng lọc dải thông 0,5–5 Hz để cô lập dao động pulsatile.
3. Trong bơm chậm: phát hiện dao động đạt ngưỡng đủ lớn để ghi P_sys_est.
4. Gửi T, P_sys_est + margin xuống MCU.
5. Trong xả chậm: xây envelope và chạy MAA để hiển thị MAP/SBP/DBP.

## 4.3 Kiểm thử được khuyến nghị

Checklist trong Firmware/TESTING.md và Firmware/testcase.md hướng dẫn các nhóm thử:
Nhóm an toàn (SAF):
- STOP khi đang bơm: bơm tắt ngay, van mở tối đa, LED đỏ nhấp nháy nhanh.
- Trần 280 mmHg: MCU cắt bơm và báo động.
- Lệnh T,300: firmware clamp về 280.
- ABORT/A: xả nhanh như STOP phần cứng về hành vi an toàn.
Nhóm UART:
- Kiểm tra 100 khung S,.../giây trong inflate/deflate.
- Sau T,..., MCU vào margin rồi xả đo đúng trình tự.
Nhóm LED/HMI: idle xanh; inflate vàng nhấp nháy ∼500 ms; đo/xả vàng sáng; STOP/SAF/fast deflate đỏ nhấp nháy ∼150 ms; lỗi rò/I2C đỏ sáng.

BÁO CÁO ĐỒ ÁN — EE3037 Chương 4. PHẦN MỀM HOST VÀ KIỂM THỬ

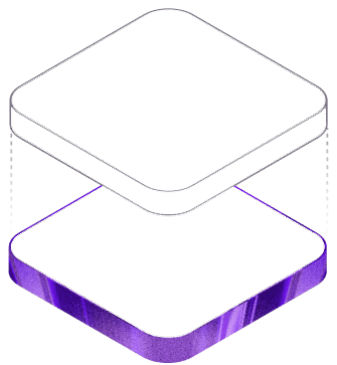
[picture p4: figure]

Figure 4.1: Minh họa giao diện WebApp (ảnh hero trong kho mã).

BÁO CÁO ĐỒ ÁN — EE3037 Chương 4. PHẦN MỀM HOST VÀ KIỂM THỬ

## 4.4 Hạn chế của kiểm thử trong phòng lab

Firefox/Safari không hỗ trợ Web Serial; có thể cần bridge TCP/socat nếu phải dùng trình duyệt khác. Đánh giá độ chính xác lâm sàng đòi hiệu chỉnh đồng hồ áp và mẫu đối chứng đủ lớn, nằm ngoài phạm vi một checklist chức năng thuần túy.

## KẾT LUẬN

## Kết quả đạt được

Đề tài đã xây dựng được một nguyên mẫu máy đo huyết áp oscillometric với đầy đủ các khối chức năng: cảm biến MPX5050, ADC ADS1115, vi điều khiển STM32F103 điều khiển bơm/van PWM và streaming UART; phần mềm WebApp trên trình duyệt hỗ trợ Web Serial để hiển thị sóng áp, lọc số và MAA nhằm suy ra MAP, SBP và DBP; cơ chế an toàn trần áp 280 mmHg và dừng khẩn cấp được triển khai đồng thời trên firmware và qua lệnh serial. Bo mạch và schematic được thể hiện trong dự án KiCad OscilloBP Monitor kèm Gerber phục vụ gia công.

## Hạn chế

Độ chính xác tuyệt đối phụ thuộc mạnh vào hiệu chỉnh offset/scale của kênh đo áp và vào bộ hệ số rs, rd của MAA; các giá trị mặc định trong tài liệu chỉ mang tính tham chiếu và cần tinh chỉnh theo dữ liệu lâm sàng hoặc bộ phép đo chuẩn. Web Serial giới hạn loại trình duyệt; đo trong điều kiện chuyển động tay hoặc nhiễu điện từ có thể làm méo envelope nếu không bổ sung lọc/outlier mạnh hơn.

## Hướng phát triển

Áp dụng hiệu chỉnh đa điểm và lưu hệ số trên EEPROM; mở rộng thuật toán (khớp đường cong Gauss, thích ứng rs, rd); tích hợp bridge TCP/WebSocket cho đa nền tảng; thực hiện thử nghiệm so sánh với máy đo đã chứng nhận y tế và hoàn thiện hồ sơ an toàn điện/khí nén cho sản phẩm.

# TÀI LIỆU THAM KHẢO

[1] NXP Semiconductors, MPX5050 / MPX5050GP — Integrated Silicon Pressure Sensor On-Chip Signal Conditioned, Temperature Compensated and Calibrated, Datasheet, truy cập qua trang nhà sản xuất.
[2] Texas Instruments, ADS1113, ADS1114, ADS1115 — Ultra-Small, Low-Power, I²C-Compatible, 860-SPS ADC With Internal Reference, Datasheet SBAS444.
[3] STMicroelectronics, STM32F103x8 / STM32F103xB — Medium-density perfor-mance line ARM-based 32-bit MCU, Reference Manual RM0008 và Datasheet DS5319.
[4] L. A. Geddes và M. Voelz, Pulse Transit Time as an Indicator of Arterial Blood Pressure, và các tài liệu cổ điển về oscillometry / characteristic ratios (tham khảo trong giáo trình đo lường y sinh).
[5] Nhóm dự án, mpx5050-blood-pressure-monitor — firmware PlatformIO, WebApp và tài liệu nội bộ (algorithm.md, pc-bridge.md, TESTING.md), Kho mã nguồn GitHub phantranthehuy/mpx5050-blood-pressure-monitor, 2026.

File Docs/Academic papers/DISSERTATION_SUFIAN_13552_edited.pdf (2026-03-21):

DESIGN OF LOW COST BLOOD PRESSURE MONITOR FOR RURAL POPULATION

By

MOHAMAD SUFIAN BIN AYUB

FINAL PROJECT REPORT

Submitted to the Electrical & Electronics Engineering Programme in Partial Fulfillment of the Requirements for the Degree
Bachelor of Engineering (Hons) (Electrical & Electronics Engineering)

Universiti Teknologi Petronas

Bandar Seri Iskandar

31750 Tronoh

Perak Darul Ridzuan

Ó Copyright 2014

by

Mohamad Sufian bin Ayub, 2014

i

CERTIFICATION OF APPROVAL

DESIGN OF LOW COST BLOOD PRESSURE MONITOR FOR RURAL POPULATION

by

Mohamad Sufian bin Ayub

A project dissertation submitted to the Electrical & Electronics Engineering Programme Universiti Teknologi PETRONAS
in partial fulfilment of the requirement for the Bachelor of Engineering (Hons) (Electrical & Electronics Engineering)

Approved:

__________________________

Assoc. Prof Dr. Fawnizu Azmadi Hussin

Project Supervisor

UNIVERSITI TEKNOLOGI PETRONAS

TRONOH, PERAK

June or December 2014

ii

CERTIFICATION OF ORIGINALITY

This is to certify that I am responsible for the work submitted in this project, that the

original work is my own except as specified in the references and acknowledgements,

and that the original work contained herein have not been undertaken or done by

unspecified sources or persons.

__________________________

MOHAMAD SUFIAN BIN AYUB

iii

ABTRACT

In this modern area, oscillometric blood pressure monitor has been widely used in

medical equipment, replacing the traditional manual sphygmomanometer, which using

the detection of Korotkoff sound to measure blood pressure. The oscillometric blood

pressure monitor has been applied being subject of many studies due to its simplicity of

use and low price. Oscillometric method of measuring blood pressure is done through the

record of cuff-pressure oscillation. The systolic blood pressure and diastolic blood

pressure is determined through the value of maximum cuff-pressure oscillation (Amax),

or also known as mean arterial pressure (MAP). This paper present the building of

oscillometric blood pressure monitor with manual pumping mechanism. Firstly the signal

is detected by pressure sensor MPX5050GP, and then filtered by OP amp LM324N. after

that, the filtered and amplified signal will be sampled by the microcontroller

PIC18F2321. The calculated blood pressure will dispayed in term of ‘pass’ and “fail’

through the lighting of LED.

iv

ACKNOWLEDGEMENTS

First and foremost, I would like to extend my gratitude to ALLAH for His

blessing and guidance in order for me to complete this Final Year Project entitled ‘Design

of Low Cost Blood Pressure Monitor for Rural Population’ throughout this 8 months.

The completion of this project would not have been possible without the hard

work and endless support for those who involved either directly or indirectly in this

report. Firstly, I would like to thank my supervisor | Assoc. Prof Dr. Fawnizu Azmadi
Hussin | for taking his time off his busy schedule to assist me in completing my final year

project. Thank you also for his encouragement and valuable advices throughout period of

conducting this project. All of his effort in providing me sufficient useful guidelines to

ensure I can complete my project in the given time, were really appreciated by me.

Special thanks to my friend, Mr. Shafiq Ashraf for his help during the fabrication

of this project and troubleshooting, as well as giving me the opportunity to learn new

knowledge. Without his help, it would be really hard for me to complete this project.

Lastly, I would like to express my biggest thanks to my parent, who always pray

for my best and always support me whenever I faced obstacles throughout completing of

this final year project. I surely hopes that the outcome of this project may benefit to

others as well.

Thank you.

i

TABLE OF CONTENT

ii

CHAPTER 6 : REFERRENCE | 27

LIST OF FIGURES

Figure 1: Basic electronic blood pressure monitor reference design block diagram. This
design is created by referring to the Freescale Medical Application. [6] | 9

Figure 2 : Mark of systolic and diastolic blood pressure. The ratio taken in respect to
Amax for both systolic and diastolic blood pressure may be varying between different
manufacturers of blood pressure monitor | 10
Figure 3: Proportional relationship of cuff pressure (CP) and blood pressure (BP) value | 11
Figure 4 : Connection of the components | 15
Figure 5: L7805CV voltage regulator | 16
Figure 6: Op-amps position inside LM324 chip | 16
Figure 7: Connection on op-amp 1 | 17
Figure 8: Connection of highpass filters and lowpass filters | 17
Figure 9: Connection on pressure sensor | 18
Figure 10: Connection on microcontroller chip | 19

LIST OF TABLES

Table 1: Classification of blood pressure | 11
Table 2: Gantt chart of the project | 21
Table 3 : Specification of pressure sensor | 24

CHAPTER 1 : INTRODUCTION

### 1.1 BACKGROUND STUDY

Our heart is an amazing organ in our body. It work reliably, and it has been safely

pumping blood to each organ in our body for decades. The blood is transported

throughout our body through blood vessels. If the heart is considered as pump, the blood

vessels will be considered as pipes [1]. A blood pressure monitoring is a crucial way for

us to check the performance of these pump and pipes.

Blood pressure is means by the pressure exerted on the wall of blood vessel by the blood

circulation, due to the pumping action of the heart. The blood pressure may be varied

between human and animal, and it is normally taken for two types of measurements. The

two types of measurements are for the minimum pressure (diastolic) and maximum

pressure (systolic) [1] . Different reading of blood pressure for both systolic and diastolic

will determine the health condition of a person. Too low record of blood pressure will

conclude that the person to suffer from hypotension and too high blood pressure record

will be considered the person to suffer from hypertension.

It is important for us to monitor the blood pressure regularly; so that immediate action

could be taken it early symptom of undesired blood pressure is detected. Nowadays,

many blood pressure monitoring devices could be purchased in the market, but to have a

cheap or low cost blood pressure monitor will be an issue. With the advancement of

technology, the blood pressure monitor could be obtained from the concept of manual

mechanism, to the automatic mechanism with the help of electronic devices.

### 1.2 PROBLEM STATEMENT

In the urban area, most of the people lived inside it are consist of people with education

and career. Furthermore, the urban area is equipped with a lot of facilities, including hospital. For this kind of person, in case that they want to seek for medical checkup or

advice from the doctor, they will go by themselves to the hospital by their own transport

or by the public transports which can be easily get in the urban area. Plus, since they are

consisting of careered person, most of them are affordable to pay for the medical

expenses.

Unfortunately, in the scope of Malaysia, Malaysian citizen are also consisting of poor

people who live alone, single mother, and old people, and they are live in the rural area.

For all this poor people who live in this rural area, they might aware of their health

condition, but they may be reluctant to seek for medical checkup in hospital, as they poor

health condition prevent them to travel, or they do not have transport to go there, or they

are not affordable to pay the medical expense. In addition, it might be difficult for them

to obtained the public transport due to the population in rural area. As the government

and non-government hospital aware about this matter, their management has put some

effort in approaching the people in this rural area, but sometimes they might face some

difficulties to entertain every villages in one rural area.

Due to this problem, the body of Corporate Social Responsibility of Universiti Teknologi

PETRONAS (UTP-CSR) has been collaborated with the local hospital under the

Malaysia Ministry of Health to held a social service with the local resident outside the

university campus. The main target resident for this event is the folks of Kampung Aji,

Bota, Perak. The majority folks living in the village were consist of old people, with

some of them with poor health condition.

The duty of volunteer of UTP-CSR was to do the scheduled medical checkup on the

residents, including doing the blood pressure monitoring. As to purchase the existing

blood pressure monitor devices in the market is considered as costly, UTP-CSR has plan

to invent our own blood pressure monitor device that is low cost, and easy to use. The

design of the device will be done, in such way that it will be easy for the untrained

volunteers to use it to measure blood pressure, without much expertise.

### 1.3 OBJECTIVES

1. To invent a low cost blood pressure monitor device
2. To create a blood pressure monitor that is easy to be used by the person who is

untrained in measuring blood pressure.

### 1.4 SCOPE OF STUDY

There are two types of blood pressure monitors (or also known as sphygmomanometer)

that widely used and available in the market nowadays. The type of blood pressure

monitors are manual blood pressure monitor and automatic blood pressure monitor. For

the manual blood pressure monitors, there are two common types of it, which is mercury

sphygmomanometer and aneroid sphygmomanometer. For the automatic blood pressure

monitor, the measurement of the blood pressure was done by two methods, which is

automated auscultatory method and oscillometric method.

Most of blood pressure monitors available in the market nowadays are the one that

provided with the hand cuff. The hand cuff is used to wrap the upper arm in order to

apply pressure for the blood pressure measurement. However, there are also non-invasive

blood pressure monitor that does not require the hand cuff for the blood pressure

measurement. This non-invasive blood pressure monitor is normally consisting of small

cuff that is used by placing it around the wrist or fingertip. The mechanism is the same

with the one that is used in normal automatic oscillometric blood pressure monitor, but in

term of accuracy, this type of blood pressure monitor has faced some issues.

Mercury blood pressure monitor is consisting of a high vertical column with mercury

contained inside it, a hand cuff and also the bulb. The mercury-filled column is used as

the pressure gauge. The bulb is used to manually pump air inside the hand cuff in as the

hand cuff is placed around the upper arm. The measurement of the blood pressure is done

by using auscultatory method. The blood pressure is determined by examining the height

of the mercury inside the column, as response to the pressure applied to the hand cuff.

For the aneroid blood pressure monitor, the mechanism and the method of measurement is the same with the one that is used in mercury blood pressure monitor, but the pressure

gauge is replaced with barometer dial.

The electronic blood pressure monitor is consisting of some sensors and other electronic

parts, depending on the method used in device. The pumping mechanism of the air inside

the hand cuff is automatically done with the combination of the mechanical part

electronic part of the blood pressure monitor. The blood pressure is determined through

some electronic calculations. The reading of the blood pressure is displayed by using

electronic display.

CHAPTER 2 : LITERATURE REVIEW

### 2.1 HISTORY OF BLOOD PRESSURE MONITOR

The history of blood pressure monitoring was started at 1733, when Reverend Stephen

Hales started to explore his study in animal physiology, by measuring the blood pressure

in several animal species. Most famously, he has inserted a long tube, which was made

up from glass, upright into an incision in an artery of a horse. In this experiment, it has

been realized that the pumping action of the horse’s heart generated a pressure force that

causing the blood to flow and rise into the glass tube. In advance, Hales also took wax

casts of the ventricle of the heart, and estimated how much blood has been pumped by the

heart. This method has been correctly describing the function of mitral valve and aortic

valve during systolic and diastolic, which later has been widely used in the medical world

up until today. Nevertheless, these procedures were dangerous to be applied on humans,

due to the risk of excessive blood loss and infections.

In 1854, a new discovery that contribute to the innovation of blood pressure monitoring

was made when Karl von Vierordt, a German physician, create a mechanism called

sphygmograph that was used to estimate blood pressure. The mechanism was consist of

some weight and levers. Through this invention, he discover that a non-invasive blood

pressure reading could only be taken of the pulse was stopped. This research has been

followed up by Samuel Ritter von Basch, a doctor from Vienna. In 1881, he started to

create a simple design of sphygmomanometer that consist of rubber bulb filled with water

and a vertical column of glass filled with mercury; called mercury manometer. The

rubber bulb was attached to the mercury manometer. The manometer was used to

measure the pressure exerted by the fluid, which is equal to the amount of pressure to

obviate the pulse. The recorded pressure required was known as the blood pressure

reading.

The blood pressure monitoring begins to improvise when the Russian surgeon, Nikolai

Sergeyevich Korotkov (romanised as Korotkoff) describes the ‘Korotkoff sound’ through

the auscultatory technique. This technique was done by wrapping the air-filled cuff around the patient upper arm. As the cuff is inflated, it will constrain the blood arteries,

thus preventing the blood from flowing through the arteries. As the cuff is deflated back,

the arteries will be release and the blood will started to flow back. With the help of the

stethoscope, the beginning of the blood flow could be heard as the cuff is deflating. This

method has led to the increase of accuracy of blood pressure measurement. This

auscultatory technique also has been widely used by the next generation of the clinician

up until present days.

### 2.2 METHOD OF MEASURING BLOOD PRESSURE

Nowadays, the method of blood pressure monitoring has been evolved and enhanced

from day to day. The method of the blood pressure measurement as explained above is

known as auscultatory method. This method is depends to the ability of the human ear to

detect and distinguish the Korotkoff sound with other sound sourced from the

surrounding environment [2]. Thus, for the accurate result, measurement needed to be

done in a quiet environment. This method may be advantage as it allows clinician or

doctor to control the quality of the measurement. However, the hearing ability and acuity

might be different between clinicians, hence the measurement might be varies.

For many years, mercury blood pressure monitor has been the standard instrument for

measuring the blood pressure monitor in the National Health and Nutrition Examination

Survey (NHANES)[3]. However, in recent years, the usage of the mercury has been

issued by environmentalists. It is because of the increased environmental concerns about

the disposal of mercury-contaminated medical waste and the risk of spills from mercury

blood pressure monitor. Due to this matter, the clinical settings have begun phasing out

the mercury devices.

From the traditional auscultatory method, the manual mechanism of blood pressure

monitor has been evolved to the better solution, which is automatic mechanism of blood

pressure monitor. In the automatic blood pressure monitor, the continuity of the

auscultatory method is done through the automatic detection of Korotkoff sound. The audio signal will be detected by the microphone inside the cuff, which is then converted

into electric signal before it is amplified and filtered by the band pass filter and the low

pass filter[4]. The signal is then calculated by the electronic in the blood pressure monitor

through some algorithms, before the final result of systolic and diastolic blood pressure is

displayed on the screen. The pumping mechanism for inflation and deflation of the cuff is

also electronically controlled.

The other method used in the automatic blood pressure measurement is oscillometric

method. The oscillometric blood pressure monitor is composed of few electromechanical

parts, a servomotor-based air pump, and electronic valve (with permanent leakage, only

opened to deplete the cuff) and the inflatable cuff[5]. It has almost the same part compare

to the electronic blood pressure monitor that use automated auscultatory method. This

oscillometric method relies on the pressure oscillation in the hand cuff, and also with the

help of algorithm to calculate the ‘systolic’ and ‘diastolic’ blood pressure. It does not

require accurate placement on the cuff on the upper hand, nor expert clinician to take the

measurement. Nevertheless, since it depends to the brachial artery oscillation and vessel

stiffness, it may lead to inaccurate measurement for old people. In addition, there are

much more hybrid devices used in the blood pressure monitoring such as aneroid

sphygmomanometer and some other devices that use photoplethysmographic or

tonometric technique.

### 2.3 THEORY

In this project, the target is to produce a blood pressure monitor that requires the lowest

manufacturing cost. The initial proposal of this project was to build mercury blood

pressure monitor, as the materials needed to build it were cheap, except the raw mercury.

Unfortunately, the usage of mercury might lead to the hazardous chemical waste that

will finally contribute to the pollution of the environment. In addition, the usage of

mercury might expose us to the chemical contamination, due to the improper handling of

the mercury during the development of the prototype. Hence, due to the stated problem, the best option to be chosen is to create a blood pressure monitor based on electronic

mechanism.

The proposed design was to make an electronic blood pressure monitor, which is safer

and less pollution to the environment. The prototype of this project will be built from

scratch. The overall design of this prototype was inspired by the basic electronic blood

pressure monitor design, as shown in figure 1, except that the pumping mechanism of the

hand cuff is changed to the manual mechanism, instead of automated mechanism. As to

meet the objective of this project, all of the components that will be used will be set to

have as low cost as possible.

The electronic part in the blood pressure monitor is consisting of voltage regulator,

pressure sensor, transducer, OP amp (which is later to be used to build band pass filter

and low pass filter), signal conditioning and microcontroller. The pressure sensor will

measure the pressure exerted by the cuff during the inflation and deflation of the cuff.

The oscillation of pressure in the cuff measured by the pressure sensor is then converted

into electrical signal by the transducer. The electrical signal produced by the transducer

will be very small; hence it needed to be amplified by the amplifier contained in the

signal conditioning. The amplified signal with go through the band pass filter and low

pass filter to filter the unwanted noise. The signal of the recorded pressure from the

pressure sensor will be sent to the microcontroller. The microcontroller will compute the

blood pressure value before it is displayed.

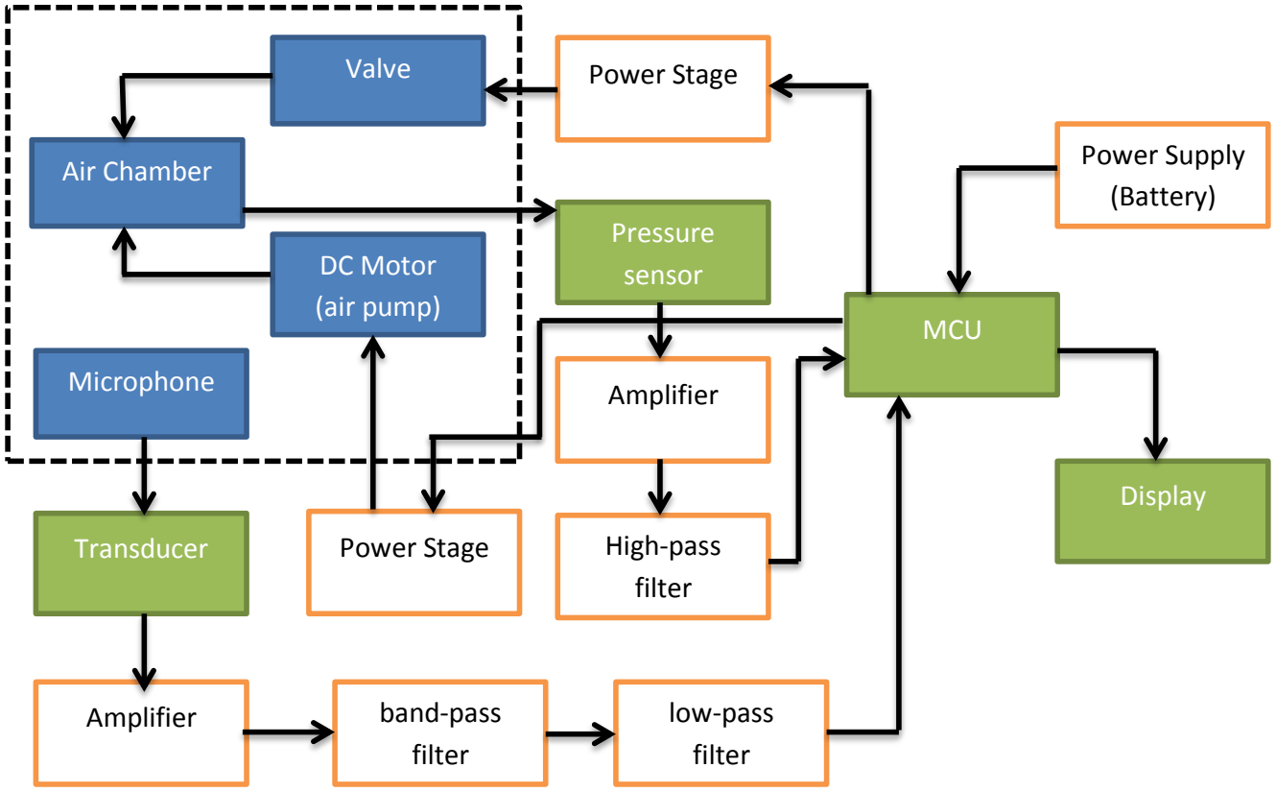
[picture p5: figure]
Valve; Air Chamber; DC Motor (air pump); Power Stage; Pressure sensor; Amplifier; High-pass filter; MCU; Display; Microphone; Transducer; band-pass; filter; low-pass filter; Power Supply (Battery)

In the process of blood pressure measurement, the system blocks brachial artery blood

flow by inflating the cuff. When the hand cuff is deflating, the blood is resuming to flow,

causing the wall of the artery to vibrate again. The vibration of the artery walls will be

change from weak to strong and then become weak again[7]. Thus, the amplitude of the

pulsatile oscillations increases to some degree and then decreases as blood flow to the

limb normalized. In order to calculate the blood pressure using the oscillometric method,

the value for the peak amplitude (Amax) need to be obtained[8]. According to the

relationship of the blood pressure value and Amax, the systolic and diastolic blood

pressure can be obtained.

Motor control of the hand cuff

Figure 1: Basic electronic blood pressure monitor reference design block diagram. This design is created by referring to the Freescale Medical Application. [6]

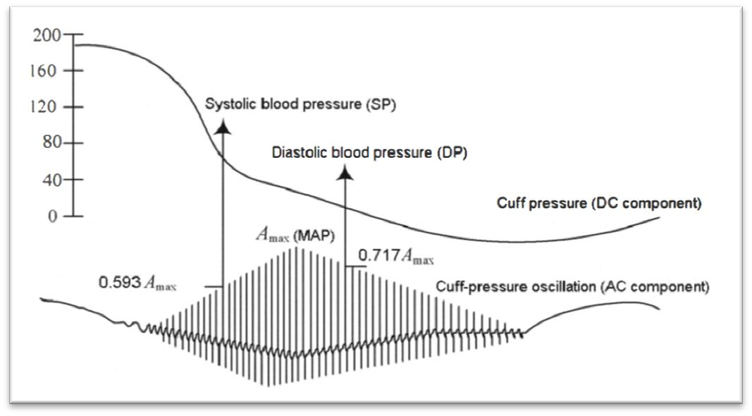
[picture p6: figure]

Figure 2 : Mark of systolic and diastolic blood pressure. The ratio taken in respect to Amax for both systolic and diastolic blood pressure may be varying between different manufacturers of blood pressure monitor.

At the same time, the voltage values of cuff pressure signal need to be converted to the

corresponding blood pressure[7]. The blood pressure is then calculated by the electronic

system in the blood pressure monitor. The measurement for a healthy person can be

classified as the table 1 below.

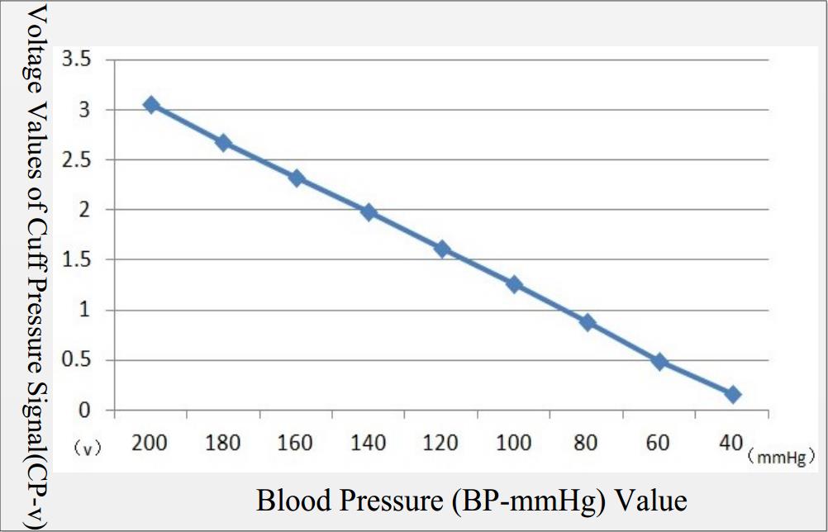
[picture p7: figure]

Figure 3: Proportional relationship of cuff pressure (CP) and blood pressure (BP) value

CATEGORY | SYSTOLIC (mmHg) | DIASTOLIC (mmHg)
Hypotension | < 90 | < 60
Desired | 90 – 119 | 60 – 79
Prehypertension | 120 – 139 | 80 – 89
Hypertension – Stage 1 | 140 – 159 | 90 – 99
Hypertension – Stage 2 | 160 – 170 | 100 – 109
Hypertension Emergency | ≥ 180 | ≥ 110

Table 1: Classification of blood pressure

CHAPTER 3 : METHODOLOGY

### 3.1 RESEARCH METHODOLOGY

For the final design of the prototype is decided, discussions has been done with the

supervisor. The initial design was to design the mercury blood pressure monitor as the

prototype, due to the concept of mercury blood pressure monitor that requires simple

materials such as PVC, hand cuff with bulb, and also raw mercury, in order to fabricate

the prototype. Unfortunately, after some discussion, it has been decided that the mercury

blood pressure monitor could not be done as prototype, as the mercury may lead to the

environmental pollution. It also may lead to the chemical contamination if the mercury

was not carefully handled during fabrication.

Due to the stated reasons, discussion has been made with the supervisor, and the design

of the prototype was changed to electronic blood pressure monitor. The proposed design

was to purchase the existing electronic blood pressure monitor in the market, and

integrating it with the android device, such as hand phone or tab. The electronic blood

pressure monitor that to be purchased will be the one with the lowest possible price, as to

minimum the cost of prototype fabrication. The purchased blood pressure monitor was

Automatic Blood Pressure Monitor BP 3BR1-1, manufactured by Microlife. Some

modifications needed to be done on the purchased blood pressure monitor. The proposed

modification was to display the calculated value of the systolic and diastolic blood

pressure on the android device. All the calculated values of systolic and diastolic will be

transferred to the android device though Bluetooth. A Bluetooth chipset will be

connected to the blood pressure monitor. A customized application will be programmed

in the android device to display the received data. Unfortunately, after some discussion

with the supervisor, it was found that the fabrication of the prototype will face some

difficulties:

1. It was difficult to connect the Bluetooth chipset to the blood pressure monitor, as the data

from the microcontroller unit was transferred to the LCD through parallel port. It was

difficult to connect the Bluetooth chipset as the chipset requires serial port for the connection. A separated circuit needed to be built to convert the parallel port into serial

port, before it is connected to the Bluetooth.

2. The transfer of the data to the android device could not be done without knowing the type

if data interpret by the microcontroller and the type of data transferred to the LCD.

Due to the stated reason, the design was changed again, which was to build the prototype

from scratch. The cost of the materials needed for the fabrication of the prototype were

ensured to be as cheap as possible, as to achieve the target of this project, which is to

create a low cost blood pressure monitor. The proposed design of this prototype will be

explain in the next part of this report.

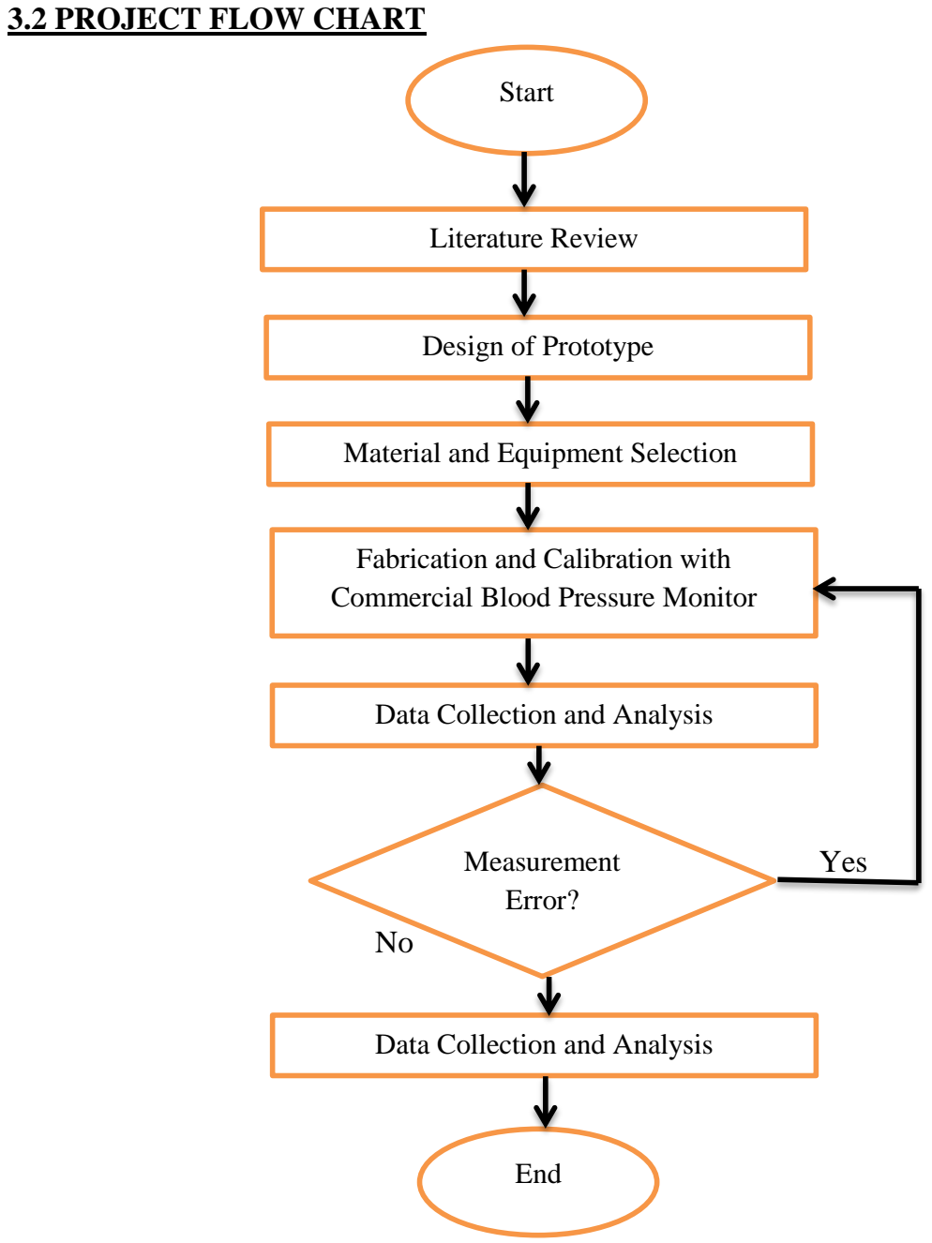
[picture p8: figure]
3.2 PROJECT FLOW CHART; Yes; Start; Literature Review; Design of Prototype; Material and Equipment Selection; Fabrication and Calibration with Commercial Blood Pressure Monitor; Data Collection and Analysis; Measurement Error?; End

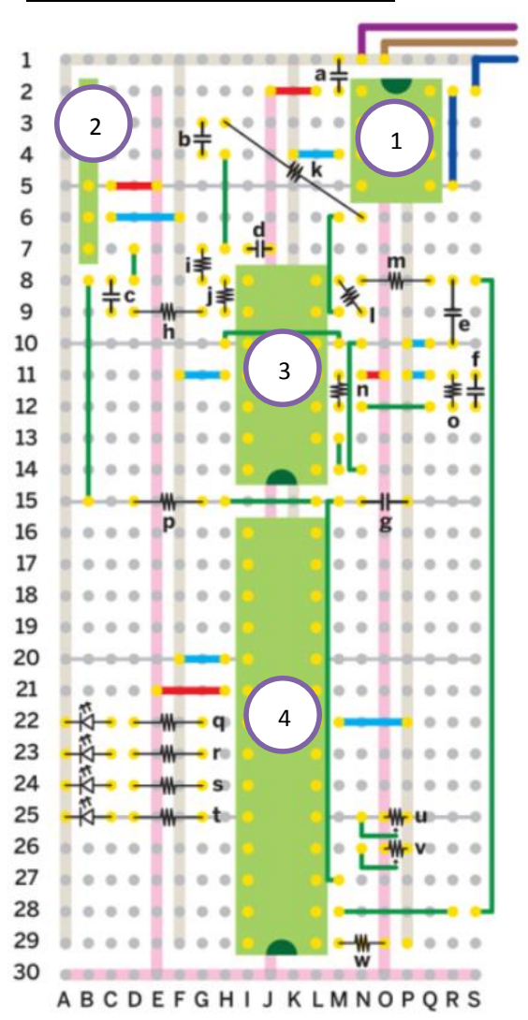
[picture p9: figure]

### 3.3 PROTOTYPE DESIGN

Other materials needed :

AA batteries, battery holder, knobs, toggle switch, potentiometer, DIP socket, LEDs,

circuit breadboard.

Key
Pink | +3.3V connection
Gray | Ground connection
Red | Wire to power source
Light blue | Wire to ground
Green | Wire
Purple | To battery ground
Brown | To crank ground
Dark blue | To switch
Label 1 | Voltage regulator
Label 2 | Pressure sensor
Label 3 | Op-Amp IC
Label 4 | Microcontroller
a | 1µF | m | 16kΩ
b | 1µF | n | 110kΩ
c | 1µF | o | 110kΩ
d | 1µF | p | 160kΩ
e | 1µF | q | 200kΩ
f | 0.1µF | r | 200kΩ
g | 1µF | s | 200kΩ
h | 160kΩ | t | 200kΩ
i | 16kΩ | u | 100kΩ
j | 750kΩ | v | 100kΩ
k | 160kΩ | w | 10kΩ
l | 750kΩ

Figure 4 : Connection of the components

### 3.4 FABRICATION OF PROTOTYPE

1. Voltage regulator is inserted into the breadboard. The type if voltage regulator used in

this project is L7805CV.

Figure 5: L7805CV voltage regulator

The ground pin is connected directly to the ground. 1µF capacitor is connected

between output pin to the ground. The output pin is also connected to the 3.3V

voltage source. 2 AA batteries is connected between input pin to the ground using

battery holder.

2. LM324 chip is inserted into the board.

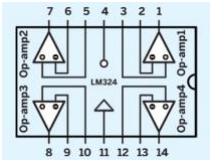
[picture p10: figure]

Figure 6: Op-amps position inside LM324 chip

Reference voltage of 1.65V is built by using op-amp 1. 0.1µF capacitor is connected

between positive terminal of op-amp 1 to the ground. Two 110kΩ resistors are

connected in parallel with the positive terminal. One 110kΩ resistor is connected

between positive terminal to the ground, and the other one 110lΩ resistor s connected

between positive terminal to the 3.3V voltage source. The output of op-amp 1 is

connected to its own negative terminal.

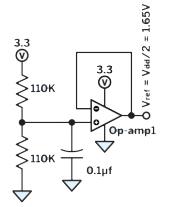
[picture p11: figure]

Figure 7: Connection on op-amp 1

3. Smoothing filters and frequency component is added into the prototype. The

smoothing filter is consisting of a bandpass filter and a lowpass filter. The bandpass

filter is constructed by cascading two highpass filter and two lowpass filter. The first

highpass filter is done by connecting 1µF capacitor is series with 160kΩ resistor. The

160kΩ resistor is connected to the negative terminal of op-amp 3, and the cap of 1µF

capacitor is connected to the output of pressure sensor. Gain is added to the op-amp 3

by connecting 750kΩ resistor between its negative terminal to its output.

4. For the lowpass filter, 16kΩ resistor is connected from the output of op-amp 3 to one

hole on the breadboard, and 1µF capacitor is connected from this hole to the ground.

The same connection of highpass and lowpass filter is created using op-amp 2, but the

cap 1µF capacitor on the highpass filter side is connected to the hole at op-amp 3 just

now.

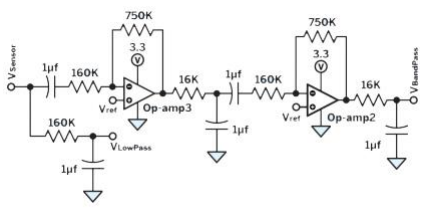
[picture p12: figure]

Figure 8: Connection of highpass filters and lowpass filters

5. The output of the second lowpass filter in op-amp 2 will be connected later with the

microcontroller pin 2 (Vbandpass).

6. For the connection of the separate lowpass filter, 160kΩ is connected from the

pressure sensor output (pin 1) to the one hole on the breadboard. From this hole, 1µF

capacitor and microcontroller pin 3 (Vlowpass) are connected to it, as shown in the

figure 8.

7. Pressure sensor is added into the circuit. The model of pressure sensor used is this

prototype is MPX5050GP. Recall to the previous step (step 6), the output of the

pressure sensor (pin 1) is connected to the 160kΩ resistor from the separate lowpass

filter. The rest of the connection on the pressure sensor is doe as shown in the figure 9

below.

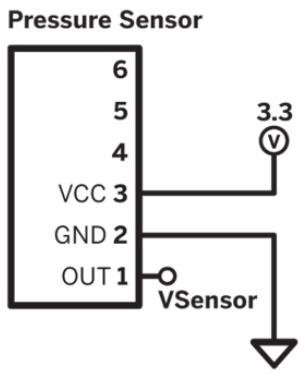
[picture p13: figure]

Figure 9: Connection on pressure sensor

8. Microcontroller chip is added into the circuit. The model of microcontroller used is

PIC18F2321. The chip is installed first with program in the form of hex file, obtained

from the website makezine.com. Power terminal is created on the microcontroller by

connecting pin 8 and 9 to the ground, and pin 20 to the 3.3V voltage supply. Pin 1 of

the chip is connected to the 3.3V power supply through 10kΩ resistor.

9. The output of the blood pressure taken will be displayed in term of PASS and FAIL.

Hence, LED will be used to indicate both pass and fail result. 4 colors of LED which

are clear (power), yellow (status), green (pass) and red (fail), will be connected on pin

21, 22, 23 and 24 respectively, through 200Ω resistor in each one of them.

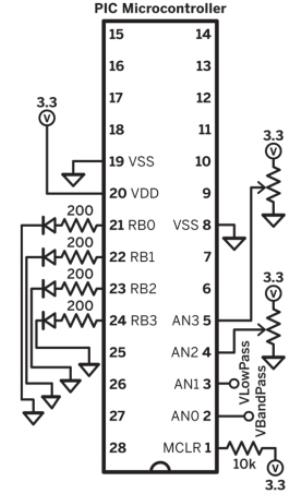
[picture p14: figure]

Figure 10: Connection on microcontroller chip

10. Two potentiometers are connected to the chip on pin 4 and 5 respectively, as shown

in figure 10 above. The potentiometer is turned fully counterclockwise. The

potentiometer connected on pin 5 is labeled as ‘Diastolic’ and the other potentiometer

connected on pin 4 is labeled as ‘Systolic’.

11. The rubber hose of the hand cuff is connected to the pressure sensor.

### 3.5 PROTOTYPE TESTING

1. Before the prototype is used, the potentiometers need to be turned fully

counterclockwise. The ideal reading for both diastolic and systolic blood pressure is

60-80mmHg and 100-120mmHg respectively. In order to calibrate the prototype, the

‘Diastolic’ potentiometer is marked as ‘60’ for the fully counterclockwise position,

and for the maximum clockwise position, the “Diastolic’ potentiometer is marked as

‘110’. Hence, for the half position between ’60’ and ‘110’, the value should be ‘85’.

(Note: All the units are in mmHg).

2. For the ‘Systolic’ potentiometer, the maximum counterclockwise position is marked

as ‘100’, and the maximum clockwise position is marked as ‘180’.

3. The prototype is switched on. The power LED is observed to blink intermittently.
4. The person of the target group needed to sit down straight and calm. The hand cuff is

attached to the person’s upper arm, just above the elbow.

5. The valve of the hand cuff is opened by turning the valve knob counterclockwise, in

order to release air inside the cuff.

6. The valve is closed back by turning it fully clockwise, and the cuff is inflated using

the hand pump. The cuff is pumped until the blood in restricted from flowing through

the vein. It is approximately 7 times of pumping in order to completely block the

blood from flowing through the vein below the hand cuff. The pumping is stopped as

the status LED lighted up.

7. The valve is then gently opened a bit in order to allow the blood to flow. The air in

the cuff is fully released until the cuff is fully deflated.

8. The pass and fail LED is observed. The pass LED (green LED) will light up if the

blood pressure reading is within the chosen value. Otherwise, the fail LED (red LED)

will light up if the pressure taken is above the chosen value.

9. Both of the pass and fail LED is lighted up when the cuff is deflating too fast. The

measurement needed to be taken again until the desired output is obtained

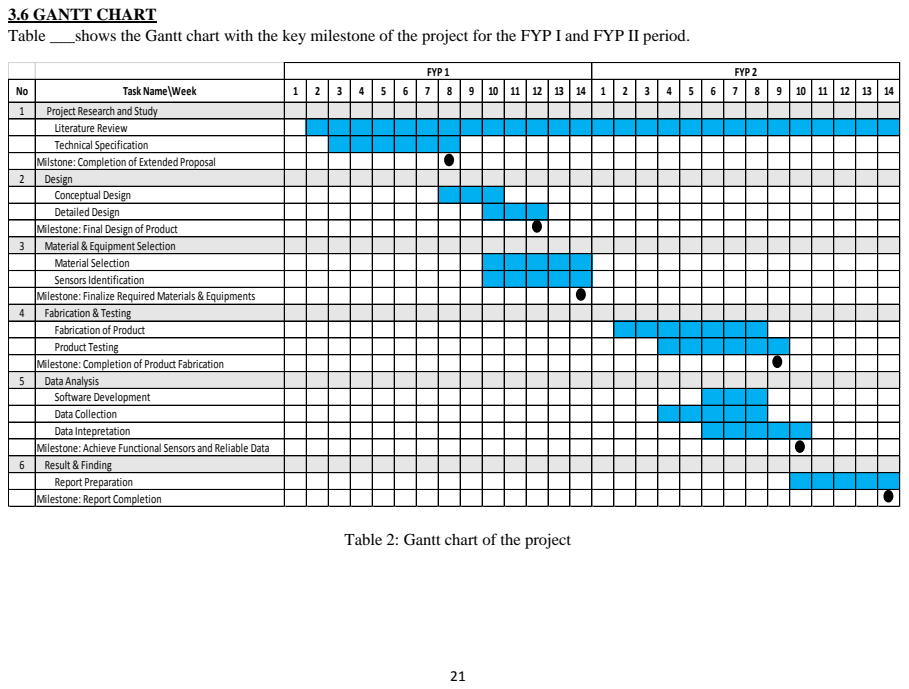
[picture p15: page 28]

3.6 GANTT CHART
Table ___shows the Gantt chart with the key milestone of the project for the FYP I and FYP II period.

FYP 1 | FYP 2

No | Task Name\Week | 1 | 2 | 3 | 4 | 5 | 6 | 7 | 8 | 9 | 10 | 11 | 12 | 13 | 14 | 1 | 2 | 3 | 4 | 5 | 6 | 7 | 8 | 9 | 10 | 11 | 12 | 13 | 14
1 | Project Research and Study
Literature Review
Technical Specification
Milstone: Completion of Extended Proposal
2 | Design
Conceptual Design
Detailed Design
Milestone: Final Design of Product
3 | Material & Equipment Selection
Material Selection
Sensors Identification
Milestone: Finalize Required Materials & Equipments
4 | Fabrication & Testing
Fabrication of Product
Product Testing
Milestone: Completion of Product Fabrication
5 | Data Analysis
Software Development
Data Collection
Data Intepretation
Milestone: Achieve Functional Sensors and Reliable Data
6 | Result & Finding
Report Preparation
Milestone: Report Completion

Table 2: Gantt chart of the project

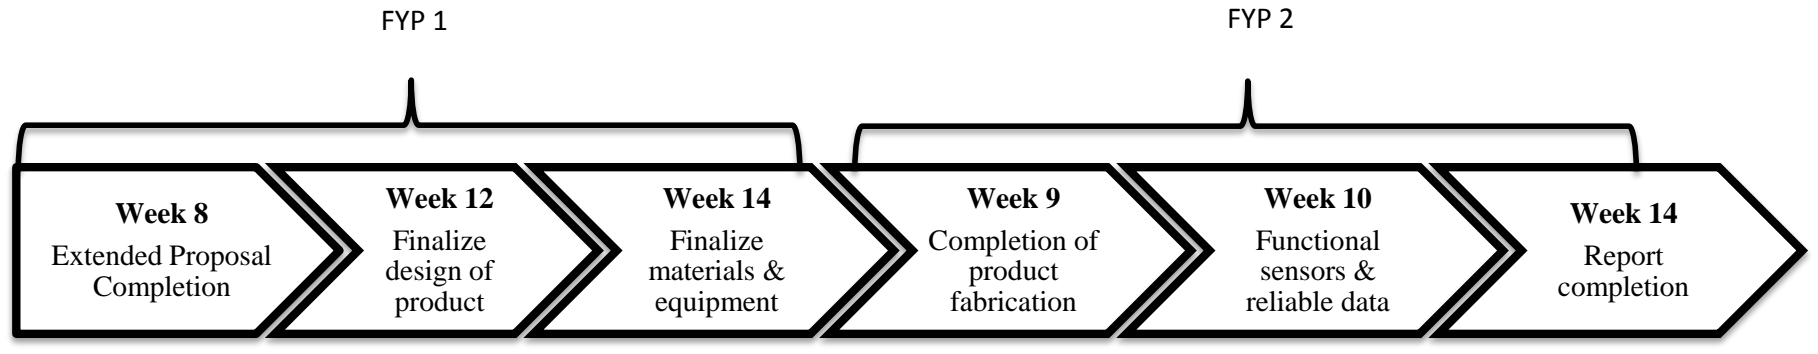
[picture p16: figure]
Week 8; Extended Proposal Completion; Week 12; Finalize design of product; Week 14; Finalize materials & equipment; Week 9; Completion of product fabrication; Week 10; Functional sensors & reliable data; Report completion; FYP 1; FYP 2

22
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

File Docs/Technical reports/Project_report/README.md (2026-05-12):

# Template Báo Cáo / Đồ Án — BKU (Bách Khoa TP.HCM)

Template LaTeX dùng cho báo cáo, đồ án môn học tại Trường ĐH Bách Khoa TP.HCM.

---

## Yêu cầu

Cài đặt một trong hai bộ sau (chọn 1):

| Bộ | Hệ điều hành | Link |
|---|---|---|
| **TeX Live** | Windows / Linux / macOS | https://www.tug.org/texlive/ |
| **MiKTeX** | Windows | https://miktex.org/ |

> Nếu dùng **VS Code**, cài thêm extension **LaTeX Workshop** để biên dịch và xem PDF ngay trong editor.

---
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

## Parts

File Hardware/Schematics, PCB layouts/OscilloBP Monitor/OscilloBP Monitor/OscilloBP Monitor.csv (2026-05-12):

Reference | Qty | Value | DNP | Exclude from BOM | Exclude from Board | Footprint | Datasheet
BT101 | 1 | Battery_Cell |  |  |  | Battery1:1x18650
C101,C102 | 2 | 22uF |  |  |  | Capacitor_SMD:C_1206_3216Metric_Pad1.33x1.80mm_HandSolder
C103,C104,C105 | 3 | 100nF |  |  |  | Capacitor_SMD:C_1206_3216Metric_Pad1.33x1.80mm_HandSolder
C201 | 1 | 1000uF - 16V |  |  |  | Capacitor_THT:CP_Radial_D16.0mm_P7.50mm
C202 | 1 | 100uF - 35V |  |  |  | Capacitor_THT:CP_Radial_D6.3mm_P2.50mm
C501,C502,C601 | 3 | 1µF |  |  |  | Capacitor_SMD:C_1206_3216Metric_Pad1.33x1.80mm_HandSolder
C602 | 1 | 10nF |  |  |  | Capacitor_SMD:C_1206_3216Metric_Pad1.33x1.80mm_HandSolder
C603 | 1 | 470pF |  |  |  | Capacitor_SMD:C_1206_3216Metric_Pad1.33x1.80mm_HandSolder
D101 | 1 | SS34 |  |  |  | Diode_SMD:D_SMA | https://www.vishay.com/docs/88751/ss32.pdf
D201,D202 | 2 | 1N5819 |  |  |  | Diode_THT:D_DO-41_SOD81_P10.16mm_Horizontal | http://www.vishay.com/docs/88525/1n5817.pdf
D401 | 1 | LED_RED |  |  |  | LED_THT:LED_D3.0mm
D402 | 1 | LED_GREEN |  |  |  | LED_THT:LED_D3.0mm
D403 | 1 | LED_YELLOW |  |  |  | LED_THT:LED_D3.0mm
FB601 | 1 | CBG201209U252T |  |  |  | Inductor_SMD:L_0805_2012Metric_Pad1.05x1.20mm_HandSolder
J101 | 1 | Conn_01x04_Pin |  |  |  | Connector_PinHeader_2.54mm:PinHeader_1x04_P2.54mm_Vertical
J102 | 1 | Conn_01x02_Pin |  |  |  | Connector_PinHeader_2.54mm:PinHeader_1x02_P2.54mm_Vertical
J201 | 1 | Terminal_01x04 |  |  |  | Connector_Phoenix_GMSTB:PhoenixContact_GMSTBA_2,5_4-G-7,62_1x04_P7.62mm_Horizontal
L101 | 1 | 22uH |  |  |  | CDRH104:CDRH104
Q201,Q202 | 2 | AO3400A |  |  |  | AO3400A:SOT95P280X125-3N
Q301,Q302 | 2 | BSS138 |  |  |  | Package_TO_SOT_SMD:SOT-23 | https://www.onsemi.com/pub/Collateral/BSS138-D.PDF
R101 | 1 | 2.2K |  |  |  | Resistor_SMD:R_1206_3216Metric_Pad1.30x1.75mm_HandSolder
R201,R203 | 2 | 100R |  |  |  | Resistor_SMD:R_1206_3216Metric_Pad1.30x1.75mm_HandSolder
R202,R204 | 2 | 4.7k |  |  |  | Resistor_SMD:R_1206_3216Metric_Pad1.30x1.75mm_HandSolder
R301,R302,R303,R304 | 4 | 10k |  |  |  | Resistor_SMD:R_1206_3216Metric_Pad1.30x1.75mm_HandSolder
R401,R402,R403 | 3 | 220R |  |  |  | Resistor_SMD:R_1206_3216Metric_Pad1.30x1.75mm_HandSolder
R501 | 1 | 1K |  |  |  | Resistor_SMD:R_1206_3216Metric_Pad1.30x1.75mm_HandSolder
R502 | 1 | 10K |  |  |  | Resistor_SMD:R_1206_3216Metric_Pad1.30x1.75mm_HandSolder
RV101 | 1 | 100K |  |  |  | Potentiometer_THT:Potentiometer_Bourns_3296W_Vertical
SW_HIGH401,SW_START401,SW_STOP401 | 3 | SW_Push |  |  |  | Button_Switch_THT:SW_PUSH_6mm_H4.3mm
U101 | 1 | TP4056 |  |  |  | TP4056_Module:TP4056_Module
U102 | 1 | MT3608 |  |  |  | Package_TO_SOT_SMD:SOT-23-6 | https://www.olimex.com/Products/Breadboarding/BB-PWR-3608/resources/MT3608.pdf
U401 | 1 | ZC323000 |  |  |  | STM32F103C8T6:STM32F103C8T6
U501 | 1 | ADS1115IDGST |  |  |  | ADS1115:ADS1115_MSOP10
U601 | 1 | MPXV5050GP |  |  |  | MPXV5050GP:SOIC127P600X175-8N

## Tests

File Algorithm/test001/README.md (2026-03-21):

# Hệ Thống Đo Huyết Áp - Peak Detection Algorithm
## Blood Pressure Measurement System - Peak Detection Algorithm

**Dự án**: MPX5050 Blood Pressure Monitor  
**Phiên bản**: 1.0  
**Ngày tạo**: 2026-03-21  
**Tác giả**: Blood Pressure Monitor Team

---

## 📋 Mục Lục (Table of Contents)

1. [Giới thiệu](#giới-thiệu)
2. [Cấu trúc Dự Án](#cấu-trúc-dự-án)
3. [Yêu Cầu Hệ Thống](#yêu-cầu-hệ-thống)
4. [Cài Đặt & Xây Dựng](#cài-đặt--xây-dựng)
5. [Hướng Dẫn Sử Dụng](#hướng-dẫn-sử-dụng)
6. [Cấu Trúc Thuật Toán](#cấu-trúc-thuật-toán)
7. [API Reference](#api-reference)
8. [Ví Dụ](#ví-dụ)
9. [Testing](#testing)
10. [Tối Ưu Hóa](#tối-ưu-hóa)
11. [Xử Lý Sự Cố](#xử-lý-sự-cố)

---

## Giới Thiệu

Dự án này cung cấp một **thuật toán dò đỉnh (Peak Detection Algorithm)** chuyên nghiệp cho hệ thống đo huyết áp
sử dụng cảm biến **MPX5050** (áp suất tuyệt đối) trên microcontroller **STM32F103**.

### Các Tính Năng Chính:
- ✅ **Lọc tín hiệu**: Loại bỏ nhiễu bằng bộ lọc thông thấp
- ✅ **Phát hiện đỉnh**: Sử dụng phương pháp zero-crossing của đạo hàm
- ✅ **Tính toán BP**: Xác định huyết áp tâm thu, tâm trương và áp suất động mạch trung bình
- ✅ **Đo nhịp tim**: Tính toán nhịp tim từ khoảng cách đỉnh
- ✅ **Xác thực dữ liệu**: Kiểm tra giá trị nằm trong phạm vi hợp lệ
- ✅ **Cấu hình linh hoạt**: Điều chỉnh hệ số bộ lọc, ngưỡng phát hiện

---

## 📁 Cấu Trúc Dự Án

```
test001/
├── CMakeLists.txt                 # CMake configuration
├── CMakePresets.json              # CMake presets
├── stm32f103x8_flash.ld           # Linker script
├── ALGORITHM_DOCUMENTATION.md     # Tài liệu thuật toán (tiếng Việt + tiếng Anh)
├── README.md                      # File này
│
├── Inc/                           # Header files
│   ├── peak_detection.h          # Peak detection algorithm headers
│   ├── sensor_interface.h        # Sensor interface and conversion
│   └── test_peak_detection.h     # Test function headers
│
├── Src/                           # Source files
│   ├── main.c                    # Main program with example usage
│   ├── peak_detection.c          # Peak detection implementation
│   ├── sensor_interface.c        # Sensor interface implementation
│   ├── test_peak_detection.c     # Test implementation
│   ├── startup_stm32f103xx.S     # Startup code
│   ├── syscall.c                 # System calls
│   └── sysmem.c                  # Memory management
│
├── cmake/                         # CMake support files
│   ├── gnu-tools-for-stm32.cmake
│   └── vscode_generated.cmake

└── build/                         # Build output (generated)
```

---

## ⚙️ Yêu Cầu Hệ Thống

### Hardware
- **MCU**: STM32F103 (hoặc tương thích)
- **Cảm Biến**: MPX5050 (hoặc cảm biến áp suất tương tự)
- **ADC**: 12-bit, tối thiểu 100Hz sampling rate

### Software
- **IDE**: Visual Studio Code + STM32 extension hoặc STM32CubeIDE
- **Compiler**: ARM GCC (arm-none-eabi-gcc)
- **CMake**: Ver. 3.20+
- **Thư viện**: Không cần thư viện bên ngoài (self-contained)

### Công Cụ Phát Triển
```bash
# Windows
- CMake 3.22+
- ARM GCC Toolchain
- STM32CubeMX (tùy chọn)

# Hoặc dùng VS Code Extensions:
- Cortex-Debug
- CMake Tools
- STM32 extension
```

---

## 🔧 Cài Đặt & Xây Dựng

### 1. Clone hoặc Copy Dự Án

```bash
cd c:\Users\Huy Hoang\mpx5050-blood-pressure-monitor\Algorithm\test001
```

### 2. Tạo Build Directory

```bash
mkdir build
cd build
```

### 3. Cấu Hình CMake

```bash
# Debug configuration
cmake -G "Unix Makefiles" -DCMAKE_BUILD_TYPE=Debug ..

# Hoặc Release
cmake -G "Unix Makefiles" -DCMAKE_BUILD_TYPE=Release ..
```

### 4. Xây Dựng Dự Án

```bash
cmake --build . --config Debug
# hoặc
make
```

### 5. Flashing sang MCU

```bash
# Dùng STM32 ST-Link
st-flash write test001.bin 0x08000000
```

---

## 📖 Hướng Dẫn Sử Dụng

### Bước 1: Khởi Tạo Hệ Thống

```c
#include "peak_detection.h"
#include "sensor_interface.h"

peak_detector_t detector;

// Khởi tạo với buffer 256 samples, tối đa 20 peaks
if (!peak_detector_init(&detector, 256, 20)) {
    printf("Initialization failed\n");
    return -1;
}
```

### Bước 2: Đặt Lại cho Lần Đo Mới

```c
// Đọc giá trị áp suất ban đầu từ cảm biến
uint16_t adc_value = read_adc();
float initial_pressure = sensor_adc_to_pressure_mmhg(adc_value);

// Đặt lại detector
peak_detector_reset(&detector, initial_pressure);
```

### Bước 3: Xử Lý Mẫu

```c
uint32_t time_ms = 0;
const uint16_t SAMPLING_PERIOD_MS = 10;  // 100Hz

while (measuring) {
    // Đọc từ ADC
    uint16_t adc_value = read_adc();
    float pressure = sensor_adc_to_pressure_mmhg(adc_value);
    
    // Xử lý mẫu
    peak_data_t *data = peak_detector_process_sample(
        &detector,
        pressure,
        time_ms
    );
    
    if (data->is_peak) {
        printf("Peak detected: %.2f mmHg\n", data->peak_magnitude);
    }
    
    time_ms += SAMPLING_PERIOD_MS;
}
```

### Bước 4: Tính Toán Kết Quả

```c
bp_measurement_t bp_result;

if (peak_detector_calculate_bp(&detector, &bp_result)) {
    if (bp_result.measurement_valid) {
        printf("Systolic:  %d mmHg\n", bp_result.systolic);
        printf("Diastolic: %d mmHg\n", bp_result.diastolic);
        printf("MAP:       %d mmHg\n", bp_result.mean_arterial);
        printf("Pulse:     %d bpm\n", bp_result.pulse_rate);
    }
}
```

### Bước 5: Dọn Dẹp

```c
peak_detector_deinit(&detector);
```

---

## 🏗️ Cấu Trúc Thuật Toán

### Quy Trình Xử Lý

```
┌─────────────────────────────────────────┐
│  Sensor (MPX5050)                       │
│  Raw Pressure Value                     │
└────────────────┬────────────────────────┘
                 ▼
┌─────────────────────────────────────────┐
│  ADC Conversion (12-bit)                │
│  ADC Value → Pressure (mmHg)            │
└────────────────┬────────────────────────┘
                 ▼
┌─────────────────────────────────────────┐
│  Low-Pass Filter (α=0.2)                │
│  Eliminate high-frequency noise         │
└────────────────┬────────────────────────┘
                 ▼
┌─────────────────────────────────────────┐
│  Derivative Calculation                 │
│  Rate of change analysis                │
└────────────────┬────────────────────────┘
                 ▼
┌─────────────────────────────────────────┐
│  Peak Detection (Zero-Crossing)         │
│  Find local maxima                      │
└────────────────┬────────────────────────┘
                 ▼
┌─────────────────────────────────────────┐
│  Peak Storage & Analysis                │
│  Store peaks with timings               │
└────────────────┬────────────────────────┘
                 ▼
┌─────────────────────────────────────────┐
│  Blood Pressure Calculation             │
│  SBP, DBP, MAP, Pulse Rate              │
└────────────────┬────────────────────────┘
                 ▼
┌─────────────────────────────────────────┐
│  Validation                             │
│  Check value ranges                     │
└────────────────┬────────────────────────┘
                 ▼
┌─────────────────────────────────────────┐
│  Result Output                          │
│  Display/Store measurements             │
└─────────────────────────────────────────┘
```

---

## 📚 API Reference

### Khởi Tạo & Quản Lý

| Hàm | Mô Tả |
|-----|---|
| `peak_detector_init()` | Khởi tạo detector, cấp phát bộ nhớ |
| `peak_detector_deinit()` | Giải phóng bộ nhớ |
| `peak_detector_reset()` | Đặt lại cho lần đo mới |

### Xử Lý Dữ Liệu

| Hàm | Mô Tả |
|-----|---|
| `peak_detector_process_sample()` | Xử lý một mẫu áp suất |
| `peak_detector_low_pass_filter()` | Lọc tín hiệu |
| `peak_detector_calculate_derivative()` | Tính đạo hàm |
| `peak_detector_detect_peak()` | Phát hiện đỉnh |

### Lấy Dữ Liệu

| Hàm | Mô Tả |
|-----|---|
| `peak_detector_get_peaks_count()` | Lấy số đỉnh phát hiện |
| `peak_detector_get_peak()` | Lấy dữ liệu đỉnh cụ thể |
| `peak_detector_calculate_bp()` | Tính toán huyết áp |
| `peak_detector_get_statistics()` | Lấy thống kê tín hiệu |

### Cấu Hình

| Hàm | Mô Tả |
|-----|---|
| `peak_detector_set_threshold()` | Đặt ngưỡng phát hiện |
| `peak_detector_set_filter_coefficient()` | Đặt hệ số bộ lọc |

---

## 📝 Ví Dụ

### Ví Dụ 1: Đo Huyết Áp Đơn Giản

```c
#include "peak_detection.h"

int main(void) {
    peak_detector_t detector;
    bp_measurement_t result;
    
    // Khởi tạo
    peak_detector_init(&detector, 256, 20);
    peak_detector_reset(&detector, 80.0f);
    
    // Giả sử có dữ liệu từ cảm biến
    float pressure_samples[] = {80, 85, 90, 95, 100, 95, 90, 85, 80};
    
    for (int i = 0; i < 9; i++) {
        peak_detector_process_sample(&detector, pressure_samples[i], i*10);
    }
    
    // Tính toán
    if (peak_detector_calculate_bp(&detector, &result)) {
        if (result.measurement_valid) {
            printf("SBP: %d, DBP: %d\n", result.systolic, result.diastolic);
        }
    }
    
    peak_detector_deinit(&detector);
    return 0;
}
```

### Ví Dụ 2: Điều Chỉnh Thông Số Bộ Lọc

```c
// Nếu tín hiệu có nhiều nhiễu
peak_detector_set_filter_coefficient(&detector, 0.1);  // α nhỏ = lọc nhiều hơn

// Nếu cần phản ứng nhanh hơn
peak_detector_set_filter_coefficient(&detector, 0.4);  // α lớn = phản ứng nhanh
```

### Ví Dụ 3: Lấy Thống Kê

```c
float min_p, max_p, mean_p;
peak_detector_get_statistics(&detector, &min_p, &max_p, &mean_p);
printf("Min: %.2f, Max: %.2f, Mean: %.2f\n", min_p, max_p, mean_p);
```

---

## 🧪 Testing

### Chạy Test Suite

```bash
# Compile với test functions
# (test_peak_detection.c được compile)

# Gọi từ main hoặc debug
if (run_all_tests()) {
    printf("✓ All tests passed\n");
} else {
    printf("✗ Some tests failed\n");
}
```

### Các Test Hiện Có

1. **Test Realistic Measurement**: Dữ liệu huyết áp thực tế bình thường
2. **Test Noisy Data**: Dữ liệu có nhiễu nhân tạo
3. **Test Edge Cases**: Các trường hợp biên
4. **Test Filter Response**: Kiểm tra ngoại lệ bộ lọc

---

## ⚡ Tối Ưu Hóa

### 1. Hiệu Suất Bộ Nhớ

```c
// Giảm kích thước buffer nếu cần tiết kiệm RAM
peak_detector_init(&detector, 128, 15);  // Nhỏ hơn

// Hoặc tăng nếu cần lưu trữ dài hạn
peak_detector_init(&detector, 512, 50);  // Lớn hơn
```

### 2. Độ Chính Xác

```c
// Tần suất lấy mẫu cao hơn = độ chính xác tốt hơn
// Khuyến nghị: 100Hz (10ms) trở lên

// Điều chỉnh hệ số bộ lọc
// - Ít nhiễu: α = 0.3 - 0.4
// - Nhiễu: α = 0.1 - 0.2 (lọc nhiều)
```

### 3. Tốc Độ Tính Toán

```c
// Sử dụng fixed-point nếu cần (thay vì floating-point)
// Hạn chế số phép tính logarit/trig
// Pre-calculate hằng số
```

---

## 🐛 Xử Lý Sự Cố

### Vấn Đề: Phép Đo Không Hợp Lệ

**Nguyên nhân**: Không đủ đỉnh được phát hiện

```c
// Kiểm tra số đỉnh
printf("Peaks: %d\n", peak_detector_get_peaks_count(&detector));

// Giải pháp:
// 1. Tăng thời gian đo
// 2. Giảm hệ số bộ lọc α
// 3. Kiểm tra cảm biến
```

### Vấn Đề: Giá Trị Sai Lệch

**Nguyên nhân**: Nhiễu trong tín hiệu

```c
// Giảm hệ số bộ lọc
peak_detector_set_filter_coefficient(&detector, 0.1);

// Hoặc tăng ngưỡng phát hiện
peak_detector_set_threshold(&detector, 0.7);
```

### Vấn Đề: Không Phát Hiện Đỉnh

**Nguyên nhân**: Tín hiệu quá mịn hoặc cảm biến không hoạt động

```c
// 1. Kiểm tra cảm biếu
// 2. Kiểm tra ADC
// 3. Tăng hệ số lọc
peak_detector_set_filter_coefficient(&detector, 0.4);  // Nhạy cảm hơn
```

---

## 📊 Phạm Vi Giá Trị

| Thông Số | Tối Thiểu | Bình Thường | Tối Đa |
|---|---|---|---|
| Systolic (SBP) | 60 mmHg | 120 mmHg | 250 mmHg |
| Diastolic (DBP) | 30 mmHg | 80 mmHg | 200 mmHg |
| Pulse Rate | 30 bpm | 70 bpm | 180 bpm |
| Đỉnh tối thiểu | - | 3 | - |
| Thời gian đo | 5s | 20s | 30s |

---

## 📞 Liên Hệ & Hỗ Trợ

Nếu có câu hỏi hoặc vấn đề:

1. Kiểm tra **ALGORITHM_DOCUMENTATION.md** để hiểu rõ thuật toán
2. Xem **ví dụ** trong **main.c**
3. Chạy **test suite** để xác thực
4. Kiểm tra lại **cấu hình cảm biến**

---

## 📄 Giấy Phép

Copyright (c) 2025 - All Rights Reserved

---

## ✅ Checklist Triển Khai

- [ ] Cấu hình ADC trên STM32F103
- [ ] Kết nối MPX5050 sensor
- [ ] Xây dựng dự án
- [ ] Chạy test suite
- [ ] Flash firmware lên MCU
- [ ] Kiểm tra đầu ra trên console
- [ ] Xác thực với máy đo chính thức
- [ ] Điều chỉnh thông số nếu cần
- [ ] Lưu kết quả đo
- [ ] Triển khai trên sản phẩm

---

**Cập nhật lần cuối**: 2026-03-21  
**Phiên bản**: 1.0

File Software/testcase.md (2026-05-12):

Dựa trên bản vẽ Schematic bạn đã cung cấp, để đảm bảo hệ thống phần cứng và phần mềm hoạt động ổn định trước khi tích hợp lên WebApp, bạn cần thực hiện quy trình kiểm thử (Testing) một cách bài bản. 

Dưới đây là bộ **Testcase toàn diện (Hardware Bring-up & Functional Test)** được chia thành từng phân hệ (Subsystem) bám sát trực tiếp vào các linh kiện trên sơ đồ của bạn.

---

### PHẦN 1: KIỂM THỬ NGUỒN (POWER SUPPLY TESTS)

*Mục đích: Đảm bảo không có chạm chập và các mức điện áp cấp cho IC đều chính xác trước khi nạp code.*

| Test ID | Tính năng kiểm tra | Các bước thực hiện (Test Steps) | Kết quả mong đợi (Expected Results) |

| :--- | :--- | :--- | :--- |

| **PWR-01** | Test chạm chập (Short-circuit) | Dùng VOM đo thông mạch giữa các net: `+3.7V - DGND`, `+5V - DGND`, `+3.3V - DGND`. | VOM **KHÔNG** kêu bíp (điện trở > 1kOhm). Không có chạm chập. |

| **PWR-02** | Test Nguồn Pin (BT101) & Sạc (U101) | Cắm pin 3.7V vào BT101. Cắm cáp nguồn vào chân IN của TP4056 (U101). | Đo chân `+3.7V` (OUT+) đạt khoảng 3.7V - 4.2V. Đèn báo sạc trên board sáng. |

| **PWR-03** | Test Mạch Boost 5V (U102) | Cấp nguồn pin. Đo điện áp tại ngõ ra của cuộn cảm L101 / Diode D101 / Tụ C101. | Điện áp đo được ở net `+5V` phải đạt chính xác **5.0V** (điều chỉnh biến trở RV101 nếu cần). |

| **PWR-04** | Test Nguồn Logic (MCU/Cảm biến) | Đo điện áp tại chân cung cấp cho MCU (net `+3.3V`) và chân VDD của cảm biến. | Net `+3.3V` đạt ~3.3V. Net `+5V` tại chân 2 (VS) của MPX5050GP đạt 5V. |

---

### PHẦN 2: KIỂM THỬ KHỐI VI ĐIỀU KHIỂN & NGOẠI VI (MCU & PERIPHERALS)

*Mục đích: Đảm bảo MCU sống, nạp được code và giao tiếp cơ bản với các ngoại vi.*

| Test ID | Tính năng kiểm tra | Các bước thực hiện (Test Steps) | Kết quả mong đợi (Expected Results) |

| :--- | :--- | :--- | :--- |

| **MCU-01** | Nạp Firmware | Cắm mạch nạp ST-Link vào `SW_START`, `SW_STOP` (hoặc SWCLK, SWDIO). Nạp code chớp tắt LED. | MCU nạp code thành công. LED hoạt động. |

| **IO-01** | Đọc Nút nhấn (BUTTON) | Nhấn lần lượt `SW_START`, `SW_STOP`, `SW_HIGH`. Theo dõi trạng thái GPIO trên chế độ Debug. | Trạng thái GPIO thay đổi từ HIGH xuống LOW (vì có kéo trở nội/ngoại). |

| **IO-02** | Điều khiển LED | Viết code xuất mức logic HIGH/LOW ra các chân của `D401` (Đỏ), `D402` (Xanh lá), `D403` (Vàng). | Các LED sáng/tắt tương ứng theo lệnh. Độ sáng tốt (nhờ trở 220R). |

| **COM-01** | Giao tiếp UART | Viết code gửi chuỗi "Hello WebApp" qua `UART_TX` (J101). Kết nối USB-TTL xem trên máy tính. | Terminal PC hiển thị đúng chuỗi với Baudrate 115200. Không bị lỗi font. |

---

### PHẦN 3: KIỂM THỬ CƠ CẤU CHẤP HÀNH (PWM & DRIVER)

*Mục đích: Kiểm tra khả năng đóng ngắt dòng điện lớn cho Bơm và Van khí.*

| Test ID | Tính năng kiểm tra | Các bước thực hiện (Test Steps) | Kết quả mong đợi (Expected Results) |

| :--- | :--- | :--- | :--- |

| **DRV-01** | MOSFET Bơm (Q201 - AO3400A) | Xuất PWM 50% và 100% ra chân `PWM_Motor`. Dùng VOM hoặc Osilloscope đo tại J201. | Động cơ bơm quay. Ở PWM 50% bơm yếu hơn 100%. MOSFET Q201 không bị nóng ran. |

| **DRV-02** | MOSFET Van (Q202 - AO3400A) | Xuất PWM 0%, 30% và 100% ra chân `PWM_Valve`. | Van xả đóng chặt ở 0% (hoặc 100% tùy loại van thường đóng/mở). Van xả từ từ ở 30%. |

| **DRV-03** | Test Diode Xả (D201, D202) | Cho Bơm/Van hoạt động và tắt đột ngột. Đo tín hiệu tại chân Drain của Mosfet. | Diode 1N5819 dập tắt xung áp ngược (Flyback), không có xung điện áp âm làm hỏng MCU. |

---

### PHẦN 4: KIỂM THỬ KHỐI CẢM BIẾN & XỬ LÝ TÍN HIỆU TƯƠNG TỰ (SENSOR & ADC_BLOCK)

*Mục đích: Đảm bảo tín hiệu áp suất được số hoá với độ nhiễu thấp nhất.*

| Test ID | Tính năng kiểm tra | Các bước thực hiện (Test Steps) | Kết quả mong đợi (Expected Results) |

| :--- | :--- | :--- | :--- |

| **SEN-01** | Giao tiếp I2C Level Shifter | Scan I2C bus trên STM32 (qua mạch dịch mức Q301, Q302). | Tìm thấy địa chỉ I2C của ADS1115 là `0x48` (theo Note trên schematic: Default I2C Address = 1001000). |

| **SEN-02** | Đọc ADC tĩnh (0 mmHg) | Để hở vòng bít (không bơm). Đọc giá trị ADC từ U501 (kênh AIN0). | ADC trả về một giá trị cố định (Offset của cảm biến). Dao động nhiễu (noise) phải rất nhỏ (vài LSB). |

| **SEN-03** | Tuyến tính cảm biến | Bơm một lượng khí nhất định, kẹp chặt ống. Đọc lại giá trị ADC. | Giá trị ADC tăng lên đáng kể và giữ ổn định, không bị trôi (Drift) quá nhiều. |

---

### PHẦN 5: KIỂM THỬ CHỨC NĂNG HỆ THỐNG (SYSTEM INTEGRATION & STATE MACHINE)

*Mục đích: Giả lập quy trình đo huyết áp thực tế phối hợp giữa Hardware và thuật toán.*

| Test ID | Tính năng kiểm tra | Các bước thực hiện (Test Steps) | Kết quả mong đợi (Expected Results) |

| :--- | :--- | :--- | :--- |

| **SYS-01** | Trạng thái INFLATE (Bơm) | Quấn vòng bít vào tay. Nhấn `SW_START`. | Bơm chạy 100%. Van đóng chặt. Áp suất tăng dần trên đồ thị. Đạt ~160mmHg thì bơm tự động dừng. |

| **SYS-02** | Trạng thái DEFLATE (Xả từ từ) | Ngay sau khi bơm dừng. | Van mở một góc nhỏ (PWM ~30-40%). Áp suất giảm đều đặn từ 2-3 mmHg/giây. |

| **SYS-03** | Trích xuất tín hiệu (WebApp/UART) | Theo dõi chuỗi UART đẩy lên máy tính liên tục trong lúc xả (Ví dụ: `D,120.5,1.2`). | Trên WebApp vẽ được 2 đồ thị: Đường DC (giảm dần mượt mà) và Đường AC (có các đỉnh dao động nhịp tim). |

| **SYS-04** | Trạng thái CALCULATE & END | Sau khi áp suất DC giảm xuống dưới 40mmHg. | Van mở 100% để xả nhanh khí còn dư. Thuật toán tính toán và trả về kết quả SYS/DIA/HR hợp lý (VD: 120/80). |

---

### PHẦN 6: KIỂM THỬ AN TOÀN VÀ XỬ LÝ LỖI (SAFETY & EDGE CASES)

*Mục đích: Đây là thiết bị y tế, tiêu chuẩn an toàn là tối thượng. Thiết bị KHÔNG ĐƯỢC làm tổn thương tay người dùng.*

| Test ID | Tính năng kiểm tra | Các bước thực hiện (Test Steps) | Kết quả mong đợi (Expected Results) |

| :--- | :--- | :--- | :--- |

| **SAF-01** | Bấm dừng khẩn cấp | Đang bơm nửa chừng (hoặc đang xả), nhấn nút `SW_STOP`. | Bơm TẮT NGAY LẬP TỨC. Van MỞ 100% ngay lập tức. Đèn Red chớp báo hiệu. |

| **SAF-02** | Cắt quá áp bằng Firmware | Ghi đè code bơm liên tục. Chặn không cho van xả. | Khi áp suất ADC đọc được vượt quá **trần SAF hiệu lực** (mặc định 175 mmHg, có thể đổi UART `SAF`/`SAFH`), Firmware phải tự động ngắt Bơm và mở Van 100% (Safety Limit). |

| **SAF-03** | Lỗi hở vòng bít (Timeout) | Không cắm vòng bít vào máy. Nhấn Start. | Bơm chạy nhưng áp suất ADC không tăng. Sau 10 giây (Timeout), hệ thống báo lỗi hở khí, tự tắt bơm. |

| **SAF-04** | Lỗi đứt dây cảm biến | Rút chân SDA/SCL hoặc ngắt nguồn cảm biến MPX5050. | Hàm đọc I2C trả về lỗi. Hệ thống vào trạng thái Error, không cho phép bật Bơm. |

---

**Lời khuyên cho kỹ sư phát triển:** 

Bạn nên in bảng này ra thành Check-list. Cứ làm xong hàm C nào hoặc hàn xong cụm linh kiện nào, bạn test và tích (✓) vào đó. Qua được 100% các Test case này, hệ thống của bạn hoàn toàn đủ tiêu chuẩn để demo và bảo vệ dự án một cách cực kỳ tự tin!

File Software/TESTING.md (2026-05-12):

# Checklist kiểm thử firmware (bổ sung plan)

Ghi chú kết quả (✓ / ngày / ghi chú). Tham chiếu đầy đủ phần cứng: [`testcase.md`](testcase.md).

## An toàn & SAF

| ID | Mục | Kỳ vọng |
|----|-----|---|
| SAF-T01 | **SAF-01** STOP đang bơm | Nhấn `SW_STOP`: bơm tắt ngay, van mở tối đa, đỏ nhấp nháy nhanh (~150 ms) |
| SAF-T02 | **SAF-02** trần **175 mmHg** (mặc định; có thể đổi `SAF`/`SAFH` UART) | Áp ≥ trần hiệu lực: bơm ngắt, van mở, LED khẩn cấp |
| SAF-T03 | Lệnh `T,300` | Host gửi target > SAF hiệu lực → firmware clamp đúng trần (không vượt SAF) |
| SAF-T04 | `ABORT` / `A` serial | Trong đo: xả nhanh + LED khẩn cấp như STOP |

## UART đóng vòng

| ID | Mục | Kỳ vọng |
|----|-----|---|
| COM-T01 | Stream `S,...` | Trong inflate/deflate: ~100 dòng/giây; Arduino: `S` đầy đủ trường debug (xem `pc-bridge.md`) |
| COM-T02 | `T,<mmHg>` | Sau detect ảo: MCU chuyển `A,INFLATE_MARGIN`, ramp tới target (≤ trần SAF hiệu lực) |
| COM-T03 | Mất serial giữa chừng | Fallback inflate timeout; SAF/STOP vẫn hoạt động |
| COM-T04 | `SAF` / `SAFH` / `HIGH` | Gửi từ WebApp: MCU chấp nhận; quá áp / clamp `T` theo trần đã đặt |

## LED / HMI (LED_Algorithm)

| ID | Trạng thái | Kỳ vọng |
|----|---|---|
| LED-T01 | Idle | Xanh sáng (PB14), đỏ/vàng tắt |
| LED-T02 | Inflate slow/margin | Vàng nhấp nháy ~500 ms (PB15) |
| LED-T03 | Deflate measure | Vàng sáng giữ |
| LED-T04 | Fast deflate sau đo (P≤40) | Vàng sáng giữ (không đỏ nhấp nháy) |
| LED-T05 | STOP / SAF / ABORT fast | Đỏ nhấp nháy ~150 ms (PB13) |
| LED-T06 | Error (leak/I2C) | Đỏ sáng liên tục |

## Chức năng đo (tham testcase SYS)

| ID | Mục | Kỳ vọng |
|----|-----|---|
| SYS-T01 | Start → bơm chậm | `A,INFLATE_SLOW`, áp tăng ~10 mmHg/s (điều chỉnh PWM) |
| SYS-T02 | WebApp gửi `T,...` | Chuyển margin rồi deflate khi đạt target |
| SYS-T03 | Deflate | `A,DEFLATE`, stream tiếp cho envelope WebApp |
| SYS-T04 | Kết thúc | `E,MEAS_END`, về idle xanh |

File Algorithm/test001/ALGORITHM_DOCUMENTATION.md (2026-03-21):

/**
 ******************************************************************************
 * @file           : ALGORITHM_DOCUMENTATION.md
 * @brief          : Peak Detection Algorithm for Blood Pressure Measurement
 * @author         : Blood Pressure Monitor Team
 * @date           : 2026-03-21
 ******************************************************************************
 */

# Thuật Toán Dò Đỉnh Trong Đo Huyết Áp
## Peak Detection Algorithm for Blood Pressure Measurement

---

## 1. Giới Thiệu (Introduction)

Thuật toán dò đỉnh (Peak Detection Algorithm) là một phương pháp quan trọng trong việc đo huyết áp bằng
phương pháp dao động (Oscillometric Method). Thuật toán này phân tích tín hiệu áp suất để:

1. **Phát hiện các đỉnh** (peaks) trong tín hiệu áp suất
2. **Tính toán huyết áp tâm thu** (Systolic) - áp suất cực đại
3. **Tính toán huyết áp tâm trương** (Diastolic) - áp suất cực tiểu
4. **Ước tính nhịp tim** (Pulse Rate)

---

## 2. Nguyên Lý Hoạt Động (Operating Principle)

### 2.1 Phương Pháp Oscillometric
Khi bơm không khí vào bộ phận quấn của máy đo huyết áp, cánh tay trải qua ba giai đoạn:

- **Giai đoạn 1**: Áp suất > Huyết áp tâm thu (SBP) → Không có dao động
- **Giai đoạn 2**: Áp suất giữa Diastolic và Systolic → Dao động cực đại
- **Giai đoạn 3**: Áp suất < Huyết áp tâm trương (DBP) → Không có dao động

### 2.2 Quá Trình Xử Lý Tín Hiệu

```
Tín hiệu thô từ cảm biến
        ↓
    [Lọc Tín Hiệu] - Low-Pass Filter
        ↓
    [Tính Đạo Hàm] - Calculate Derivative
        ↓
    [Phát Hiện Đỉnh] - Peak Detection (Zero-Crossing)
        ↓
    [Phân Tích Đỉnh] - Peak Analysis
        ↓
    [Tính Toán BP] - Calculate Blood Pressure
```

---

## 3. Các Thành Phần Chính (Key Components)

### 3.1 Lọc Tín Hiệu (Low-Pass Filter)
```
formula: filtered[n] = α * raw[n] + (1-α) * filtered[n-1]
- α = 0.2 (filter coefficient)
- Loại bỏ nhiễu tần số cao
- Làm mịn tín hiệu áp suất
```

**Tác dụng:**
- Giảm nhiễu từ độ rung, cở động
- Làm mịn tín hiệu để phát hiện đỉnh chính xác

### 3.2 Phát Hiện Đỉnh (Peak Detection)
Sử dụng phương pháp **Zero-Crossing** của đạo hàm:

```
Peak Detection Logic:
if (derivative[n-1] > 0 AND derivative[n] < -threshold)
    → Peak detected at point n
```

**Quy trình:**
1. Tính đạo hàm (rate of change) của tín hiệu lọc
2. Phát hiện khi đạo hàm đổi từ dương thành âm (điểm cực đại)
3. Xác nhận đỉnh nếu cách đỉnh trước ít nhất 300ms

### 3.3 Tính Toán Huyết Áp (Blood Pressure Calculation)

```
Systolic (SBP)  = Baseline + MAX(peak magnitudes)
Diastolic (DBP) = Baseline + MIN(peak magnitudes)
MAP             = Baseline + MEAN(peak magnitudes)
Pulse Rate      = (Số đỉnh - 1) * 60 / Thời gian (bpm)
```

---

## 4. Cấu Trúc Dữ Liệu (Data Structures)

### 4.1 Peak Data Structure
```c
typedef struct {
    float pressure_value;      // Giá trị áp suất tại đỉnh
    float derivative;          // Đạo hàm (tốc độ thay đổi)
    uint32_t timestamp;        // Thời gian (ms)
    bool is_peak;              // Là đỉnh hay không
    float peak_magnitude;      // Độ lớn của đỉnh
} peak_data_t;
```

### 4.2 Blood Pressure Measurement Structure
```c
typedef struct {
    uint16_t systolic;         // Huyết áp tâm thu (mmHg)
    uint16_t diastolic;        // Huyết áp tâm trương (mmHg)
    uint16_t mean_arterial;    // Áp suất động mạch trung bình (mmHg)
    uint16_t pulse_rate;       // Nhịp tim (bpm)
    bool measurement_valid;    // Phép đo có hiệu lực
} bp_measurement_t;
```

### 4.3 Peak Detector State Machine
```c
typedef struct {
    float *pressure_buffer;    // Bộ nhớ đệm áp suất
    float *filtered_buffer;    // Tín hiệu lọc
    peak_data_t *peaks_buffer; // Bộ nhớ đệm đỉnh phát hiện
    uint16_t peaks_count;      // Số lượng đỉnh phát hiện
    float baseline_pressure;   // Áp suất cơ sở (mmHg)
    float alpha;               // Hệ số bộ lọc (0.0 - 1.0)
    ...
} peak_detector_t;
```

---

## 5. Các Hàm Chính (Main Functions)

### 5.1 Khởi Tạo
```c
bool peak_detector_init(peak_detector_t *detector, 
                       uint16_t buffer_size, 
                       uint16_t max_peaks);
```
- Cấp phát bộ nhớ cho các bộ đệm
- Khởi tạo các tham số
- Trả về true nếu thành công

### 5.2 Tái Đặt (Reset)
```c
void peak_detector_reset(peak_detector_t *detector, 
                        float baseline_pressure);
```
- Đặt lại trạng thái cho lần đo mới
- Thiết lập áp suất cơ sở

### 5.3 Xử Lý Mẫu (Process Sample)
```c
peak_data_t* peak_detector_process_sample(peak_detector_t *detector, 
                                         float pressure_value, 
                                         uint32_t timestamp);
```
- Nhận giá trị áp suất thô
- Lọc, tính toán, phát hiện đỉnh
- Trả về dữ liệu phân tích

### 5.4 Tính Toán Huyết Áp (Calculate BP)
```c
bool peak_detector_calculate_bp(peak_detector_t *detector, 
                               bp_measurement_t *measurement);
```
- Phân tích tất cả đỉnh phát hiện
- Tính toán SBP, DBP, MAP, nhịp tim
- Xác thực kết quả
- Trả về true nếu phép đo hợp lệ

---

## 6. Tham Số Cấu Hình (Configuration Parameters)

| Tham số | Giá trị | Ý nghĩa |
|---|---|---|
| `PEAK_DETECTION_ALPHA` | 0.2 | Hệ số bộ lọc thông thấp |
| `MIN_PEAKS_FOR_VALID_BP` | 3 | Số đỉnh tối thiểu cho phép đo |
| `DERIVATIVE_ZERO_CROSSING_THRESH` | 0.01 | Ngưỡng phát hiện đỉnh |
| `MIN_PEAK_DISTANCE_MS` | 300 | Khoảng cách đỉnh tối thiểu (ms) |
| `MAX_MEASUREMENT_DURATION_MS` | 30000 | Thời lượng đo tối đa (30s) |

---

## 7. Ví Dụ Sử Dụng (Usage Example)

### 7.1 Khởi Tạo Hệ Thống
```c
#include "peak_detection.h"
#include "sensor_interface.h"

peak_detector_t detector;

// Khởi tạo
peak_detector_init(&detector, 256, 20);  // Buffer: 256 samples, Max: 20 peaks

// Đặt lại cho lần đo mới (áp suất ban đầu từ cảm biến)
peak_detector_reset(&detector, 40.0);  // mmHg
```

### 7.2 Xử Lý Dữ Liệu
```c
uint16_t adc_value = read_adc();  // Đọc từ ADC
float pressure = sensor_adc_to_pressure_mmhg(adc_value);

// Xử lý mẫu
peak_data_t *result = peak_detector_process_sample(&detector, pressure, time_ms);

if (result->is_peak) {
    // Phát hiện đỉnh - có thể ghi log, bật LED, etc.
    on_peak_detected(result->peak_magnitude);
}
```

### 7.3 Tính Toán Kết Quả
```c
bp_measurement_t bp;

if (peak_detector_get_peaks_count(&detector) >= 5) {
    if (peak_detector_calculate_bp(&detector, &bp)) {
        if (bp.measurement_valid) {
            printf("SBP: %d, DBP: %d, MAP: %d, HR: %d\n",
                   bp.systolic, bp.diastolic, bp.mean_arterial, bp.pulse_rate);
        }
    }
}
```

### 7.4 Dọn Dẹp
```c
peak_detector_deinit(&detector);  // Giải phóng bộ nhớ
```

---

## 8. Chuyển Đổi Cảm Biến (Sensor Conversion)

### 8.1 MPX5050 Sensor
- **Phạm vi áp suất**: 0 - 350 kPa
- **Đầu ra điện áp**: 0.2V - 4.7V
- **Vref STM32**: 3.3V
- **ADC**: 12-bit (0-4095)

### 8.2 Công Thức Chuyển Đổi
```
1. ADC → Điện áp:
   V = (ADC_value / 4095) * 3.3V

2. Điện áp → Áp suất (kPa):
   P = (V - 0.2) / (4.7 - 0.2) * (350 - 0)
   P = (V - 0.2) * 77.1930

3. kPa → mmHg:
   P_mmHg = P_kPa * 7.50061

4. Trực tiếp ADC → mmHg:
   P_mmHg = ((ADC_value / 4095) * 3.3 - 0.2) * 77.1930 * 7.50061
```

---

## 9. Kiểm Chứng Phép Đo (Measurement Validation)

Phép đo được coi là **hợp lệ** khi:

1. ✓ Có ít nhất **3 đỉnh** được phát hiện
2. ✓ **Systolic > Diastolic**
3. ✓ **60 mmHg ≤ Systolic ≤ 250 mmHg**
4. ✓ **30 mmHg ≤ Diastolic ≤ 200 mmHg**
5. ✓ **Thời lượng đo ≤ 30 giây**

---

## 10. Tối Ưu Hóa Hiệu Suất (Performance Optimization)

### 10.1 Điều Chỉnh Hệ Số Bộ Lọc
```c
// Nhiều nhiễu → α nhỏ hơn (ví dụ: 0.1)
peak_detector_set_filter_coefficient(&detector, 0.1);

// Ít nhiễu → α lớn hơn (ví dụ: 0.3)
peak_detector_set_filter_coefficient(&detector, 0.3);
```

### 10.2 Điều Chỉnh Ngưỡng Phát Hiện
```c
// Khó phát hiện đỉnh → Tăng ngưỡng
peak_detector_set_threshold(&detector, 0.7);

// Dễ phát hiện → Giảm ngưỡng
peak_detector_set_threshold(&detector, 0.3);
```

### 10.3 Lấy Thống Kê
```c
float min_p, max_p, mean_p;
peak_detector_get_statistics(&detector, &min_p, &max_p, &mean_p);
printf("Min: %.2f, Max: %.2f, Mean: %.2f\n", min_p, max_p, mean_p);
```

---

## 11. Xử Lý Lỗi (Error Handling)

### 11.1 Khởi Tạo Thất Bại
```c
if (!peak_detector_init(&detector, 256, 20)) {
    printf("Memory allocation failed\n");
    // Xử lý lỗi
}
```

### 11.2 Phép Đo Không Hợp Lệ
```c
if (!peak_detector_calculate_bp(&detector, &bp)) {
    printf("Measurement invalid\n");
    printf("Peaks detected: %d\n", peak_detector_get_peaks_count(&detector));
    // Yêu cầu đo lại
}
```

### 11.3 Phạm Vi Áp Suất
Nếu giá trị áp suất nằm ngoài phạm vi hợp lệ:
- **SBP < 60 mmHg** hoặc **SBP > 250 mmHg** → Lỗi
- **DBP < 30 mmHg** hoặc **DBP > 200 mmHg** → Lỗi

---

## 12. Ghi Chú Kỹ Thuật (Technical Notes)

1. **Tần Suất Lấy Mẫu**: Khuyến nghị 100Hz (10ms/mẫu)
2. **Độ Phân Giải ADC**: 12-bit tối thiểu
3. **Thời Gian Đo**: 20-30 giây cho kết quả chính xác
4. **Nhiệt Độ**: Chuẩn bị đo ở 20-25°C
5. **Vị Trí Cảm Biến**: Cánh tay ở mức tim

---

## 13. Tài Liệu Tham Khảo (References)

- MPX5050 Datasheet - NXP Semiconductors
- Oscillometric Blood Pressure Measurement - IEEE
- STM32F103 Reference Manual - STMicroelectronics
- Signal Processing for Blood Pressure Measurement

---

## 14. Tiếp Theo (Next Steps)

- [ ] Tích hợp với ADC thực tế
- [ ] Thêm UART để xuất dữ liệu
- [ ] Thêm LCD/OLED display
- [ ] Lưu dữ liệu vào flash
- [ ] Viết test case
- [ ] Xác thực với máy đo chính thức

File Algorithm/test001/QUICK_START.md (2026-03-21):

/**
 ******************************************************************************
 * @file           : QUICK_START.md
 * @brief          : Hướng Dẫn Bắt Đầu Nhanh - Quick Start Guide
 * @author         : Blood Pressure Monitor Team
 * @date           : 2026-03-21
 ******************************************************************************
 */

# 🚀 Hướng Dẫn Bắt Đầu Nhanh (Quick Start Guide)
## Peak Detection Algorithm for Blood Pressure Measurement

Tài liệu này giúp bạn bắt đầu nhanh với thuật toán dò đỉnh để đo huyết áp trong **5 phút**.

---

## ✋ 5 Bước Cơ Bản

### Bước 1: Khởi Tạo Detector (Initialization)

```c
#include "peak_detection.h"

peak_detector_t detector;

// Khởi tạo: buffer 256 mẫu, tối đa 20 đỉnh
peak_detector_init(&detector, 256, 20);
```

### Bước 2: Đặt Lại Cho Lần Đo Mới (Reset)

```c
float initial_pressure = 80.0;  // mmHg (từ cảm biến)
peak_detector_reset(&detector, initial_pressure);
```

### Bước 3: Xử Lý Mẫu (Process Data)

```c
// Trong vòng lặp đo (20-30 giây)
for (int i = 0; i < NUM_SAMPLES; i++) {
    uint16_t adc_value = read_adc();                    // Đọc ADC
    float pressure = sensor_adc_to_pressure_mmhg(adc_value);  // Chuyển đổi
    
    peak_detector_process_sample(&detector, pressure, time_ms);
    
    time_ms += 10;  // Tăng thời gian 10ms
}
```

### Bước 4: Tính Toán Kết Quả (Calculate Results)

```c
bp_measurement_t result;

if (peak_detector_calculate_bp(&detector, &result)) {
    printf("Systolic:  %d mmHg\n", result.systolic);
    printf("Diastolic: %d mmHg\n", result.diastolic);
}
```

### Bước 5: Dọn Dẹp (Cleanup)

```c
peak_detector_deinit(&detector);
```

---

## 📋 Đầy Đủ Hơn (Complete Example)

```c
#include "peak_detection.h"
#include "sensor_interface.h"
#include <stdio.h>

int main(void) {
    peak_detector_t detector;
    bp_measurement_t result;
    uint32_t time_ms = 0;
    
    // Bước 1: Khởi tạo
    printf("Initializing detector...\n");
    if (!peak_detector_init(&detector, 256, 20)) {
        printf("ERROR: Init failed!\n");
        return -1;
    }
    
    // Bước 2: Đặt lại - đợi người dùng yên ổn
    printf("Place arm and wait...\n");
    uint16_t adc_init = read_adc();
    float pressure_init = sensor_adc_to_pressure_mmhg(adc_init);
    peak_detector_reset(&detector, pressure_init);
    
    // Bước 3: Đo trong 30 giây (3000 mẫu x 10ms)
    printf("Measuring...\n");
    for (int i = 0; i < 3000; i++) {
        uint16_t adc_raw = read_adc();
        float pressure = sensor_adc_to_pressure_mmhg(adc_raw);
        
        peak_detector_process_sample(&detector, pressure, time_ms);
        time_ms += 10;
        
        // Debug: in ra mỗi 1 giây
        if (i % 100 == 0) {
            printf("  Sample %d, Pressure: %.1f mmHg\n", i, pressure);
        }
    }
    
    printf("Calculating...\n");
    
    // Bước 4: Tính toán
    if (peak_detector_calculate_bp(&detector, &result)) {
        if (result.measurement_valid) {
            printf("\n====== RESULT ======\n");
            printf("Systolic:      %d mmHg\n", result.systolic);
            printf("Diastolic:     %d mmHg\n", result.diastolic);
            printf("MAP:           %d mmHg\n", result.mean_arterial);
            printf("Heart Rate:    %d bpm\n", result.pulse_rate);
            printf("Peaks Found:   %d\n", peak_detector_get_peaks_count(&detector));
            printf("====================\n");
        } else {
            printf("ERROR: Measurement invalid! Try again.\n");
        }
    }
    
    // Bước 5: Dọn dẹp
    peak_detector_deinit(&detector);
    return 0;
}
```

---

## 🔌 ADC Configuration (STM32F103)

Để sử dụng cảm biến MPX5050:

```c
// PA0 - ADC Channel 0 (MPX5050)
// Ref: 3.3V
// Resolution: 12-bit

uint16_t read_adc(void) {
    // TODO: Implement actual ADC reading
    // Return 0-4095 (12-bit value)
    return ADC1->DR;  // Ví dụ (your actual code)
}
```

### Chuyển Đổi ADC → Áp suất (mmHg)

```c
float sensor_adc_to_pressure_mmhg(uint16_t adc_value) {
    // 1. ADC → Điện áp (3.3V Vref, 12-bit)
    float voltage = (adc_value / 4095.0f) * 3.3f;
    
    // 2. Điện áp → Áp suất (kPa) [MPX5050]
    float pressure_kpa = (voltage - 0.2f) / (4.7f - 0.2f) * 350.0f;
    
    // 3. kPa → mmHg
    float pressure_mmhg = pressure_kpa * 7.50061f;
    
    return pressure_mmhg;
}
```

---

## ⚙️ Điều Chỉnh Thông Số

### Nếu Không Phát Hiện Được Đỉnh

```c
// Giảm hệ số bộ lọc (lọc ít hơn)
peak_detector_set_filter_coefficient(&detector, 0.3);
```

### Nếu Phát Hiện Nhiều Đỉnh Giả

```c
// Tăng hệ số bộ lọc (lọc nhiều hơn)
peak_detector_set_filter_coefficient(&detector, 0.1);
```

### Giải Pháp Chung Cho Lỗi

| Vấn Đề | Giải Pháp |
|---|---|
| Không tìm được đỉnh | Tăng thời gian đo, giảm α |
| Giá trị sai lệch | Kiểm tra ADC, tăng số mẫu |
| Quá nhiều điểm đỉnh | Tăng α (tăng lọc) |
| Quá ít điểm đỉnh | Giảm α (giảm lọc) |

---

## 📊 Thông Tin Output

### Blood Pressure Measurement Structure

```c
typedef struct {
    uint16_t systolic;         // Huyết áp tâm thu (mmHg)
    uint16_t diastolic;        // Huyết áp tâm trương (mmHg)
    uint16_t mean_arterial;    // Áp suất động mạch trung bình (mmHg)
    uint16_t pulse_rate;       // Nhịp tim (bpm)
    bool measurement_valid;    // Phép đo hợp lệ?
} bp_measurement_t;
```

### Ví Dụ Output

```
Systolic:      120 mmHg     (Huyết áp tâm thu - cao nhất)
Diastolic:      80 mmHg     (Huyết áp tâm trương - thấp nhất)
MAP:            93 mmHg     (Áp suất động mạch trung bình)
Heart Rate:     72 bpm      (Nhịp tim)
Peaks Found:     7           (Số đỉnh phát hiện)
```

---

## 📂 Các File Quan Trọng

| File | Mô Tả |
|---|---|
| `peak_detection.h` | Khai báo hàm chính |
| `peak_detection.c` | Hiện thực thuật toán |
| `sensor_interface.h/c` | Chuyển đổi ADC → Áp suất |
| `main.c` | Ví dụ chính |
| `ALGORITHM_DOCUMENTATION.md` | Tài liệu chi tiết |

---

## 🧪 Kiểm Tra (Verify)

### 1. Xây Dựng (Build)

```bash
cd build
cmake -G "Unix Makefiles" -DCMAKE_BUILD_TYPE=Debug ..
cmake --build .
```

### 2. Chạy Test

```c
// Thêm vào main.c
if (run_all_tests()) {
    printf("✓ All tests passed\n");
}
```

### 3. Xác Thực Kết Quả

Kiểm tra xem kết quả có hợp lý không:
- **SBP > DBP** ✓
- **60 ≤ SBP ≤ 250** ✓
- **30 ≤ DBP ≤ 200** ✓
- **Tối thiểu 3 đỉnh phát hiện** ✓

---

## 🎯 Tóm Tắt Hàm Chính

```c
// Khởi tạo/Dọn dẹp
peak_detector_init()      // Khởi tạo
peak_detector_deinit()    // Giải phóng
peak_detector_reset()     // Đặt lại

// Xử lý
peak_detector_process_sample()  // Xử lý một mẫu

// Kết quả
peak_detector_calculate_bp()         // Tính huyết áp
peak_detector_get_peaks_count()      // Lấy số đỉnh
peak_detector_get_statistics()       // Thống kê

// Cấu hình
peak_detector_set_filter_coefficient()  // Điều chỉnh bộ lọc
peak_detector_set_threshold()           // Điều chỉnh ngưỡng
```

---

## 💡 Mẹo Hữu Ích

1. **Tần suất lấy mẫu**: 100Hz (10ms) là lý tưởng
2. **Thời gian đo**: 20-30 giây cho kết quả tốt nhất
3. **Cảm biến**: Giữ cạnh tay ở mức trái tim
4. **Bộ lọc**: Bắt đầu với α=0.2, điều chỉnh nếu cần
5. **Debug**: Dùng `printf()` để theo dõi giá trị real-time

---

## ❓ FAQ

**Q: Phép đo luôn không hợp lệ?**  
A: Kiểm tra cảm biến, ADC, và đảm bảo có đủ đỉnh (≥3)

**Q: Giá trị không chính xác?**  
A: Kiểm tra hệ số chuyển đổi ADC, tăng thời gian đo

**Q: Làm thế nào để chạy test?**  
A: Gọi `run_all_tests()` từ `main()`

**Q: Cần điều chỉnh gì ngoài α?**  
A: Kiểm tra `MIN_PEAK_DISTANCE_MS`, thời gian đo

---

## 📞 Hỗ Trợ

- 📖 Xem `ALGORITHM_DOCUMENTATION.md` để hiểu sâu hơn
- 💻 Kiểm tra `main.c` để xem ví dụ
- 🧪 Chạy `test_peak_detection.c` để xác thực
- 📊 Xem README.md để biết thêm chi tiết

---

**Hãy bắt đầu ngay!** ✨

Tài liệu này cung cấp đủ thông tin để bạn bắt đầu trong 5 phút.
Đối với chi tiết kỹ thuật, xem `ALGORITHM_DOCUMENTATION.md`.

---

**Phiên bản**: 1.0  
**Cập nhật**: 2026-03-21

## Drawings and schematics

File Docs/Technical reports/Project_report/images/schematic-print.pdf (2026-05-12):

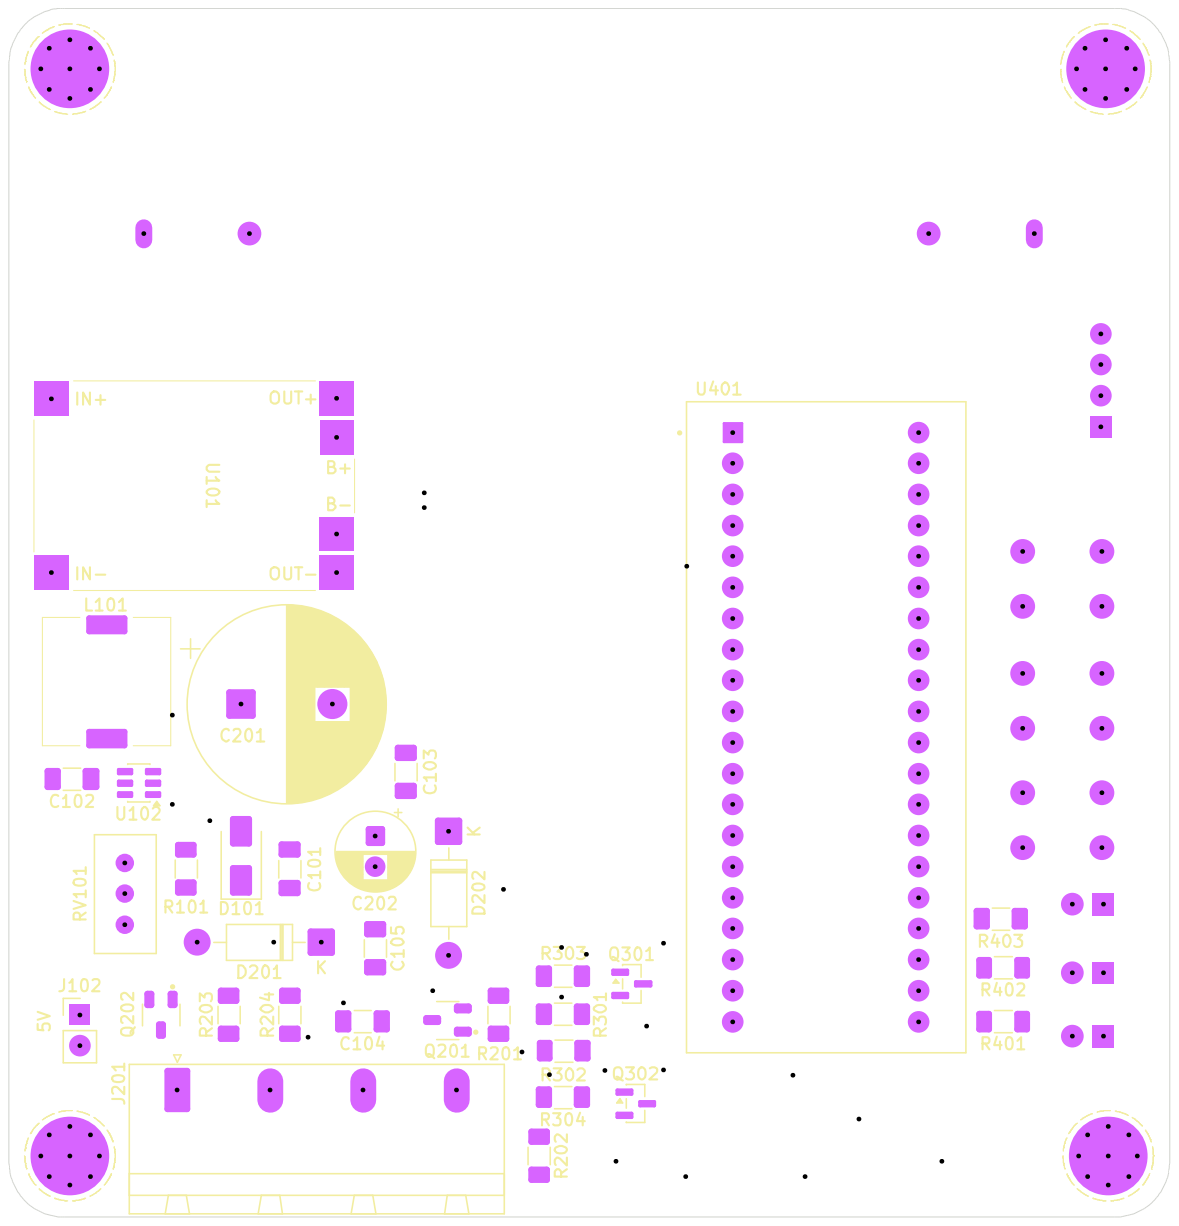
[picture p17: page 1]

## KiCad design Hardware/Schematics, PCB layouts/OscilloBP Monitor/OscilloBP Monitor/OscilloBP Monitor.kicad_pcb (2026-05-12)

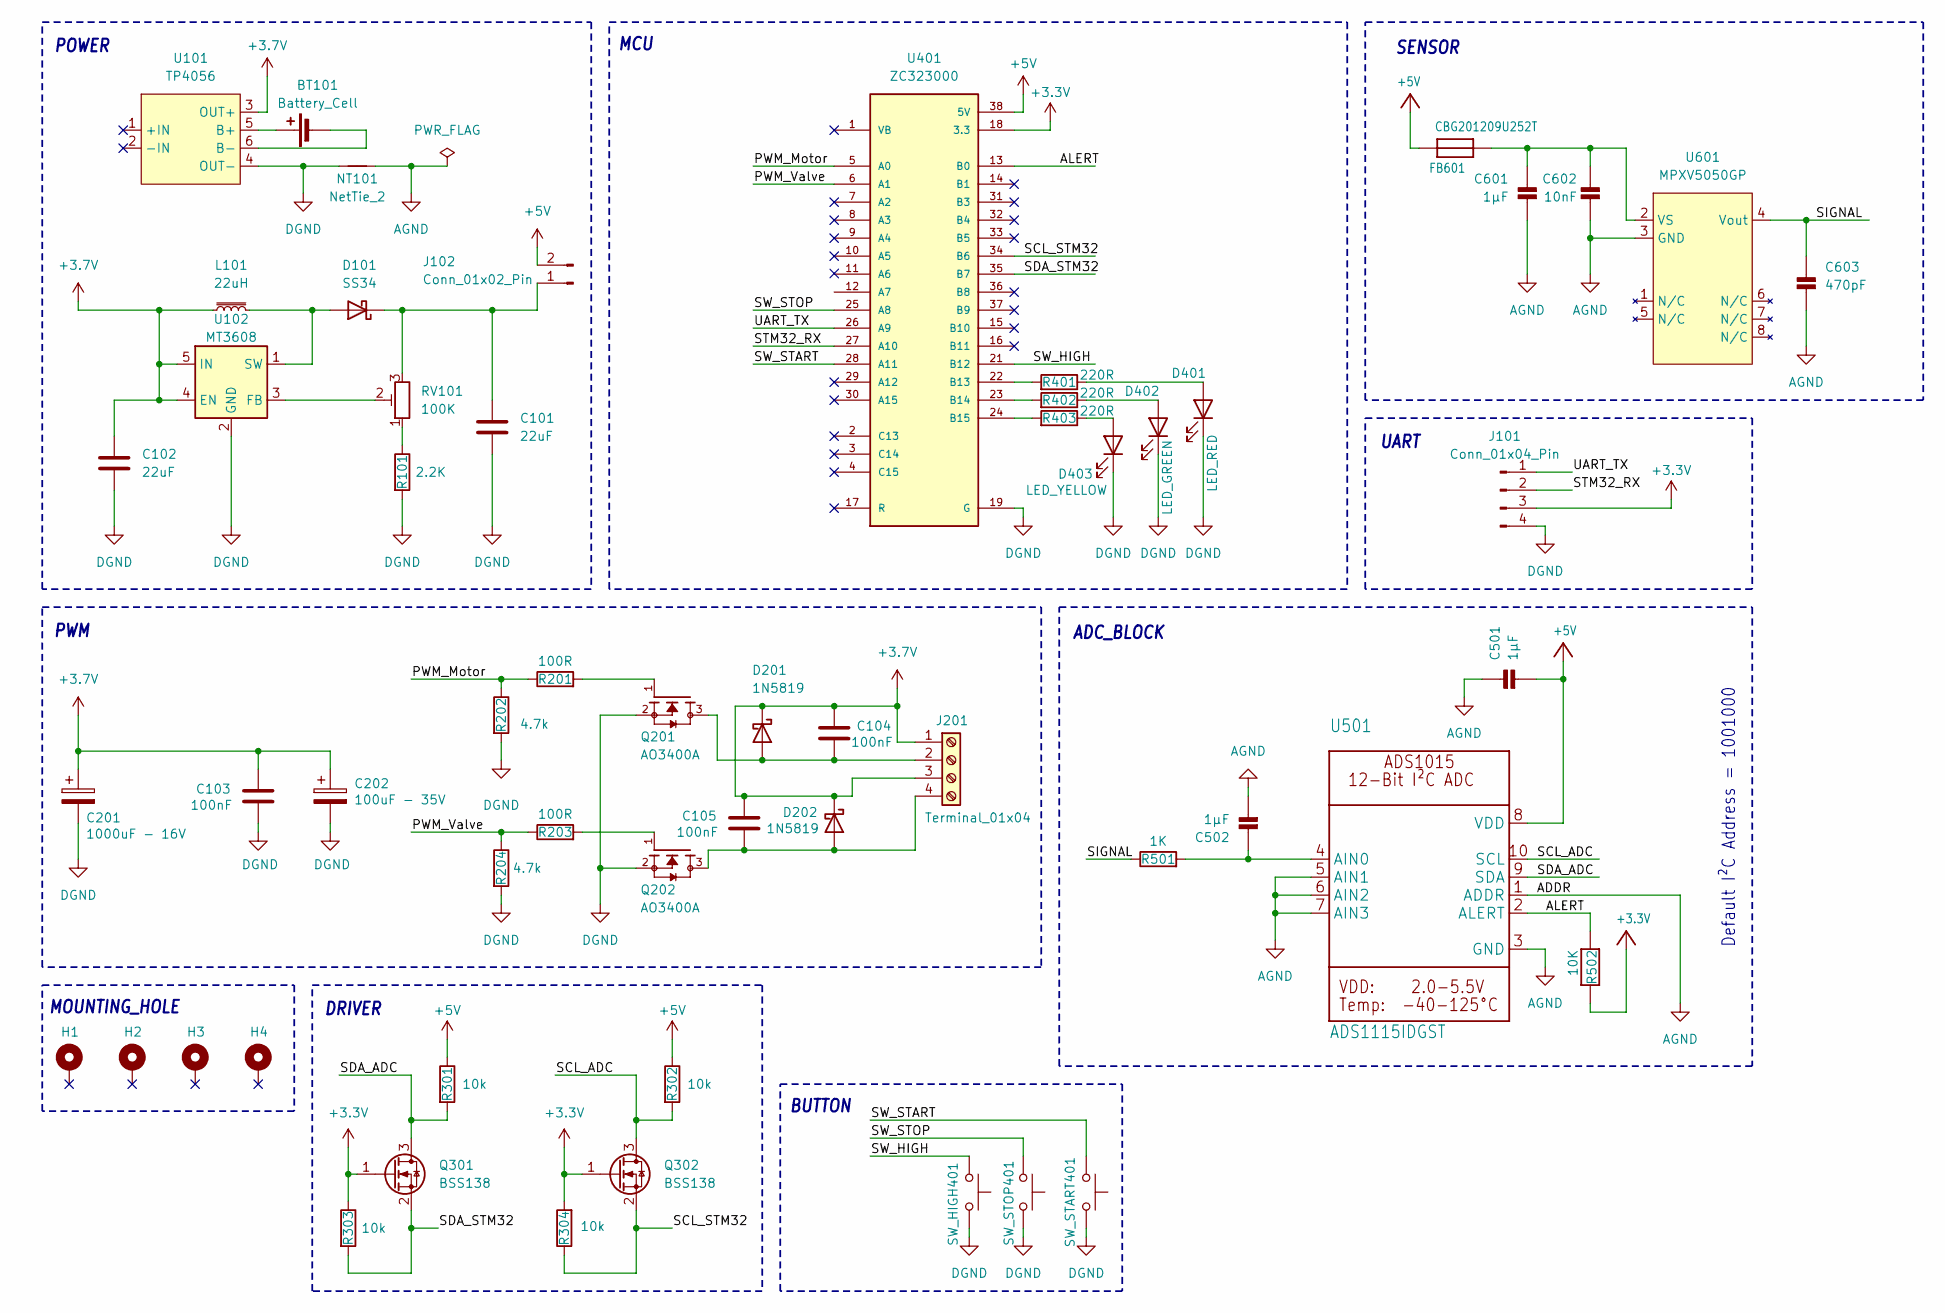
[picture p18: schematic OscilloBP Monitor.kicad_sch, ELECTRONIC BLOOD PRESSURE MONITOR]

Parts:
BT101: Battery_Cell; 1x18650
C101, C102: 22uF; C_1206_3216Metric_Pad1.33x1.80mm_HandSolder
C103, C104, C105: 100nF; C_1206_3216Metric_Pad1.33x1.80mm_HandSolder
C201: 1000uF - 16V; CP_Radial_D16.0mm_P7.50mm
C202: 100uF - 35V; CP_Radial_D6.3mm_P2.50mm
C501, C502, C601: 1µF; C_1206_3216Metric_Pad1.33x1.80mm_HandSolder
C602: 10nF; C_1206_3216Metric_Pad1.33x1.80mm_HandSolder
C603: 470pF; C_1206_3216Metric_Pad1.33x1.80mm_HandSolder
D101: SS34; D_SMA
D201, D202: 1N5819; D_DO-41_SOD81_P10.16mm_Horizontal
D401: LED_RED; LED_D3.0mm
D402: LED_GREEN; LED_D3.0mm
D403: LED_YELLOW; LED_D3.0mm
FB601: CBG201209U252T; L_0805_2012Metric_Pad1.05x1.20mm_HandSolder
H1, H2, H3, H4: MountingHole_Pad; mounting
J101: Conn_01x04_Pin; PinHeader_1x04_P2.54mm_Vertical
J102: Conn_01x02_Pin; PinHeader_1x02_P2.54mm_Vertical
J201: Terminal_01x04; PhoenixContact_GMSTBA_2,5_4-G-7,62_1x04_P7.62mm_Horizontal
L101: 22uH; CDRH104
NT101: NetTie_2; NetTie-2_THT_Pad0.3mm
Q201, Q202: AO3400A; SOT95P280X125-3N
Q301, Q302: BSS138; SOT-23
R101: 2.2K; R_1206_3216Metric_Pad1.30x1.75mm_HandSolder
R201, R203: 100R; R_1206_3216Metric_Pad1.30x1.75mm_HandSolder
R202, R204: 4.7k; R_1206_3216Metric_Pad1.30x1.75mm_HandSolder
R301, R302, R303, R304: 10k; R_1206_3216Metric_Pad1.30x1.75mm_HandSolder
R401, R402, R403: 220R; R_1206_3216Metric_Pad1.30x1.75mm_HandSolder
R501: 1K; R_1206_3216Metric_Pad1.30x1.75mm_HandSolder
R502: 10K; R_1206_3216Metric_Pad1.30x1.75mm_HandSolder
RV101: 100K; Potentiometer_Bourns_3296W_Vertical
SW_HIGH401: SW_Push; SW_PUSH_6mm_H4.3mm
SW_START401: SW_Push; SW_PUSH_6mm_H4.3mm
SW_STOP401: SW_Push; SW_PUSH_6mm_H4.3mm
U101: TP4056; TP4056_Module
U102: MT3608; SOT-23-6
U401: ZC323000; STM32F103C8T6; PARTREV N/A
U501: ADS1115IDGST; ADS1115_MSOP10
U601: MPXV5050GP; SOIC127P600X175-8N

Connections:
+3.3V: J101.3, Q301.1 (G), Q302.1 (G), R303.1, R304.2, R502.2, U401.18 (3.3), U401.40 (3.3)
+3.7V: C102.1, C103.1, C104.1, C105.1, C201.1, C202.1, D201.1 (K), D202.1 (K), J201.1, J201.3, L101.1, U101.3 (OUT+), U102.4 (EN), U102.5 (IN)
+5V: C501.2, FB601.2, J102.2, R301.1, R302.1, U401.38 (5V), U501.8 (VDD)
/ALERT: R502.1, U401.13 (B0), U501.2 (ALERT)
/PWM_Motor: R201.1, R202.1, U401.5 (A0)
/PWM_Valve: R203.1, R204.1, U401.6 (A1)
/SCL_ADC: Q302.3 (D), R302.2, U501.10 (SCL)
/SCL_STM32: Q302.2 (S), R304.1, U401.34 (B6)
/SDA_ADC: Q301.3 (D), R301.2, U501.9 (SDA)
/SDA_STM32: Q301.2 (S), R303.2, U401.35 (B7)
/SIGNAL: C603.1, R501.1, U601.4 (Vout)
/STM32_RX: J101.2, U401.27 (A10)
/SW_HIGH: SW_HIGH401.1, U401.21 (B12)
/SW_START: SW_START401.1, U401.28 (A11)
/SW_STOP: SW_STOP401.1, U401.25 (A8)
/UART_TX: J101.1, U401.26 (A9)
AGND: C501.1, C502.2, C601.2, C602.2, C603.2, NT101.2, U501.1 (ADDR), U501.3 (GND), U501.5 (AIN1), U501.6 (AIN2), U501.7 (AIN3), U601.3 (GND)
DGND: C101.2, C102.2, C103.2, C201.2, C202.2, D401.1 (K), D402.1 (K), D403.1 (K), J101.4, NT101.1, Q201.2, Q202.2, R101.2, R202.2, R204.2, SW_HIGH401.2, SW_START401.2, SW_STOP401.2, U101.4 (OUT-), U102.2 (GND), U401.19 (G), U401.20 (G), U401.39 (G)
unnamed: BT101.1 (+), U101.5 (B+)
unnamed: BT101.2 (-), U101.6 (B-)
unnamed: C502.1, R501.2, U501.4 (AIN0)
unnamed: C601.1, C602.1, FB601.1, U601.2 (VS)
unnamed: D101.2 (A), L101.2, U102.1 (SW)
unnamed: C101.1, D101.1 (K), J102.1, RV101.3
unnamed: C104.2, D201.2 (A), J201.2, Q201.3
unnamed: C105.2, D202.2 (A), J201.4, Q202.3
unnamed: D401.2 (A), R401.1
unnamed: D402.2 (A), R402.1
unnamed: D403.2 (A), R403.1
unnamed: Q201.1, R201.2
unnamed: Q202.1, R203.2
unnamed: R101.1, RV101.1
unnamed: RV101.2, U102.3 (FB)
unnamed: R401.2, U401.22 (B13)
unnamed: R402.2, U401.23 (B14)
unnamed: R403.2, U401.24 (B15)

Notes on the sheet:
BUTTON
SENSOR
PWM
MCU
ADC_BLOCK
Default I²C Address = 1001000
MOUNTING_HOLE
DRIVER
POWER
UART

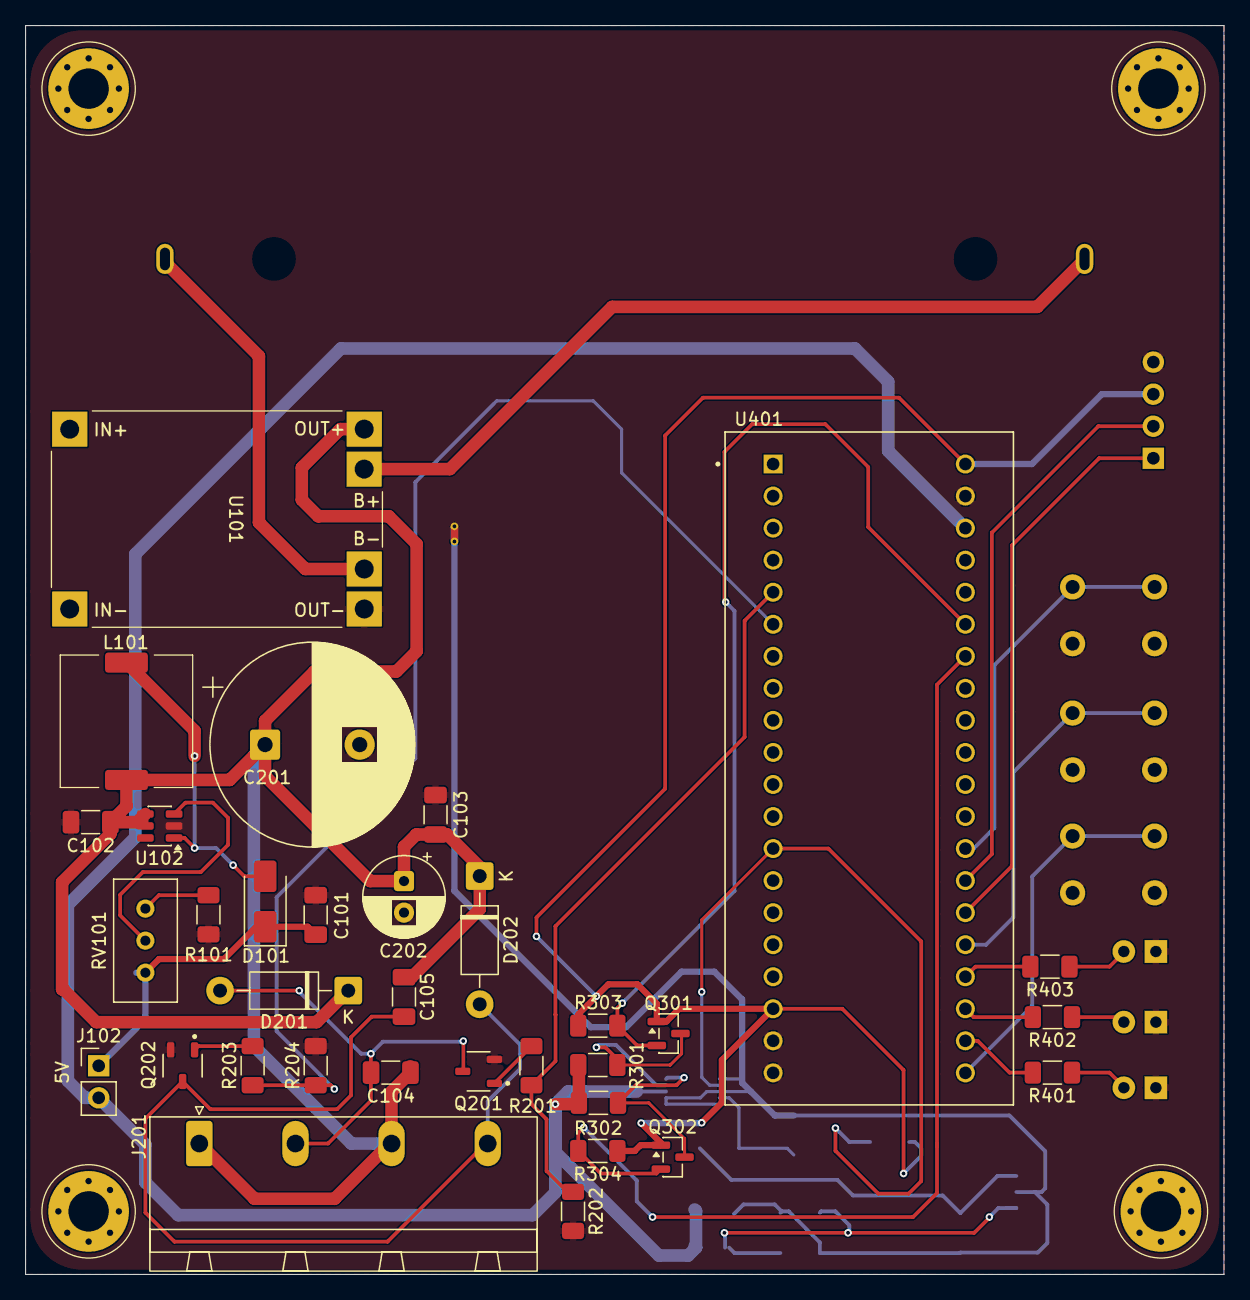
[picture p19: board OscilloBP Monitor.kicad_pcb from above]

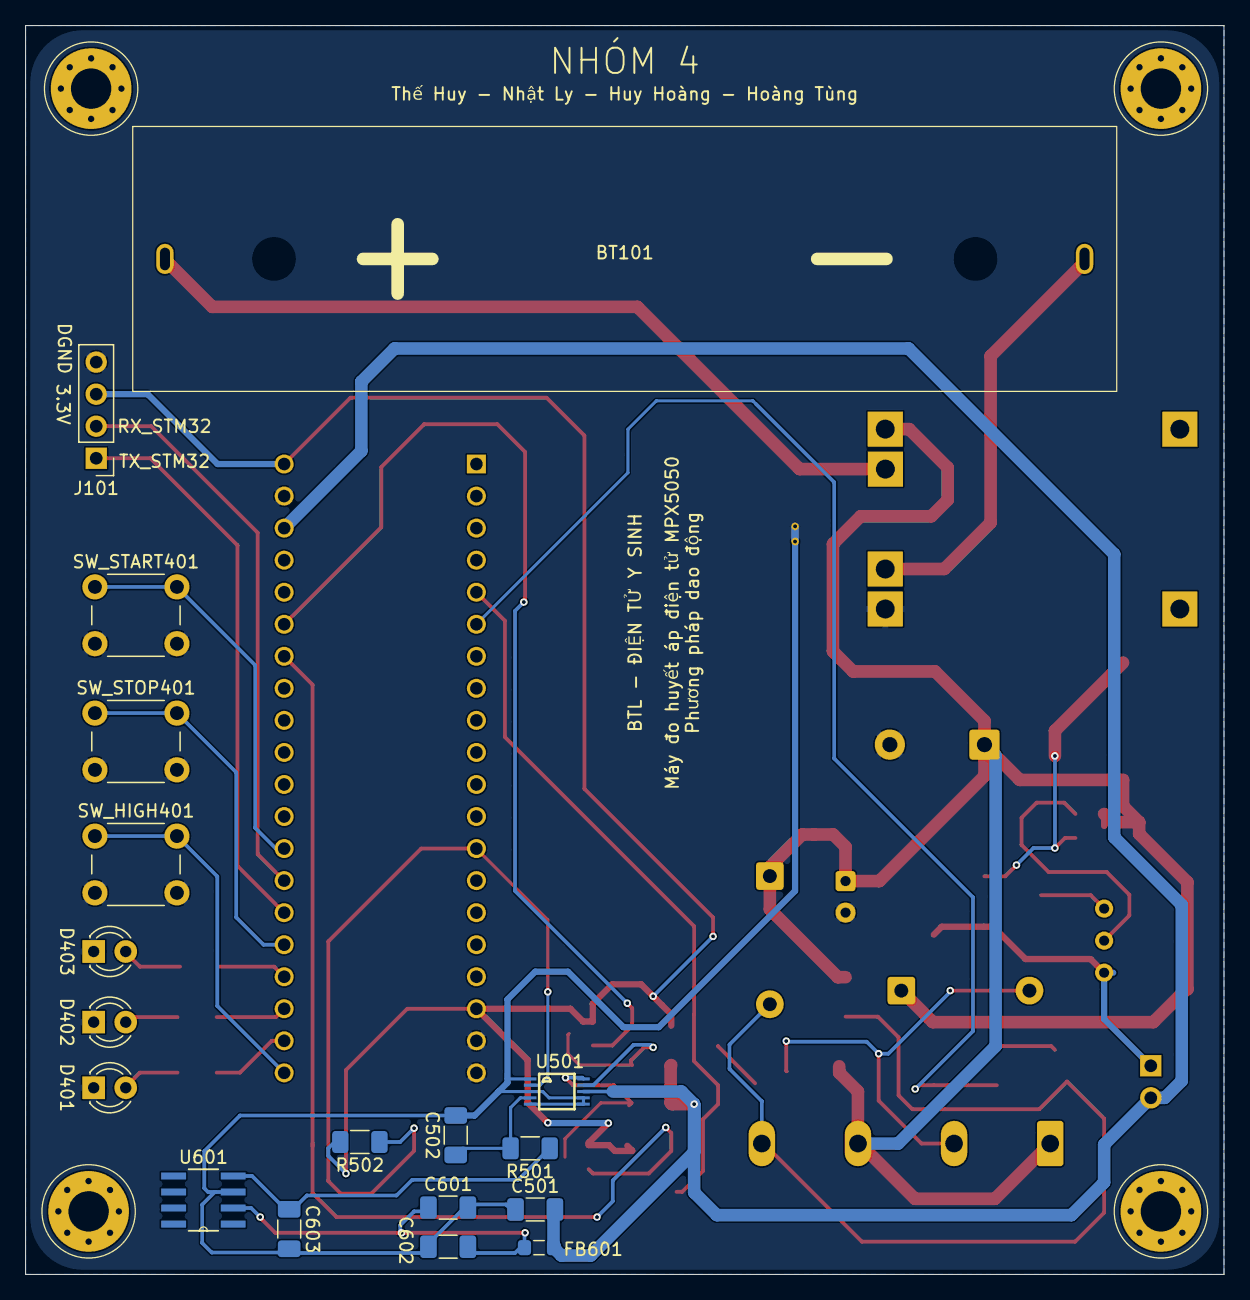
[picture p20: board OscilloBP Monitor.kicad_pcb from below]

Board: 2 copper layers, 95.0 x 99.0 mm, 56 parts (18 on the bottom side), 36 nets.

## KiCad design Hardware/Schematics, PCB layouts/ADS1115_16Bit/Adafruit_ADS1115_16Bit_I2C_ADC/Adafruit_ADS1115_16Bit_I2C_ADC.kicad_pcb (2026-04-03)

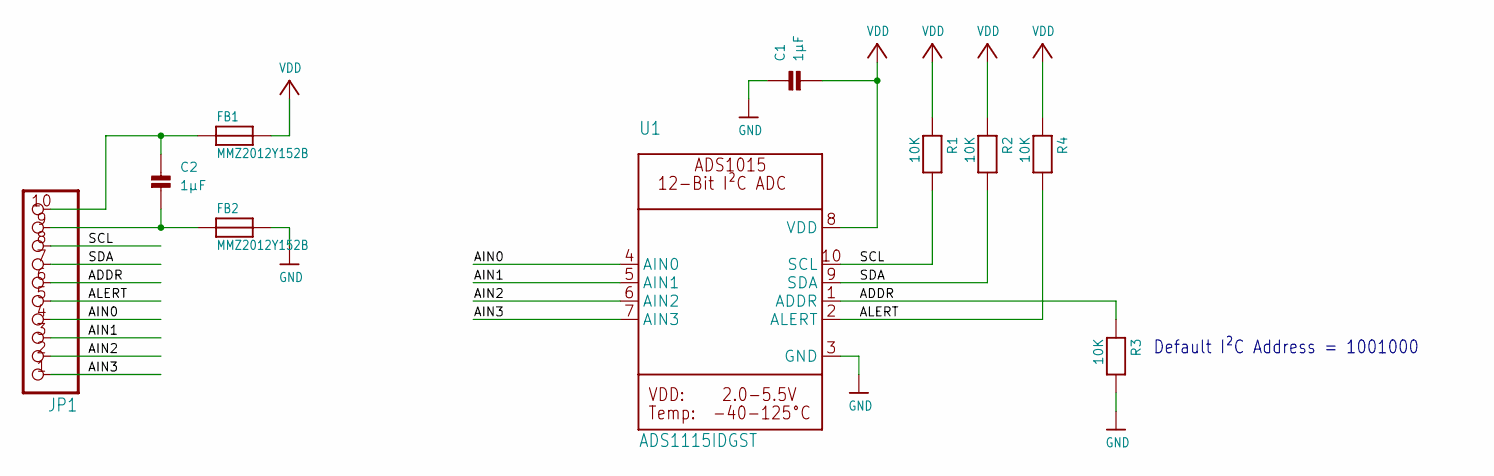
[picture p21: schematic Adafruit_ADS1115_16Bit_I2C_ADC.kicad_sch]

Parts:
C1, C2: 1µF; 0805
FB1, FB2: MMZ2012Y152B; 0805
JP1: HEADER-1X1070MIL; 1X10_ROUND70
R1, R2, R3, R4: 10K; 0805
U1: ADS1115IDGST; MSOP10

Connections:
ADDR: JP1.6, R3.1, U1.1 (ADDR)
AIN0: JP1.4, U1.4 (AIN0)
AIN1: JP1.3, U1.5 (AIN1)
AIN2: JP1.2, U1.6 (AIN2)
AIN3: JP1.1, U1.7 (AIN3)
ALERT: JP1.5, R4.2, U1.2 (ALERT)
GND: C1.1, FB2.2, R3.2, U1.3 (GND)
unnamed: C2.1, FB1.1, JP1.10
unnamed: C2.2, FB2.1, JP1.9
SCL: JP1.8, R1.2, U1.10 (SCL)
SDA: JP1.7, R2.2, U1.9 (SDA)
VDD: C1.2, FB1.2, R1.1, R2.1, R4.1, U1.8 (VDD)

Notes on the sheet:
Default I²C Address = 1001000

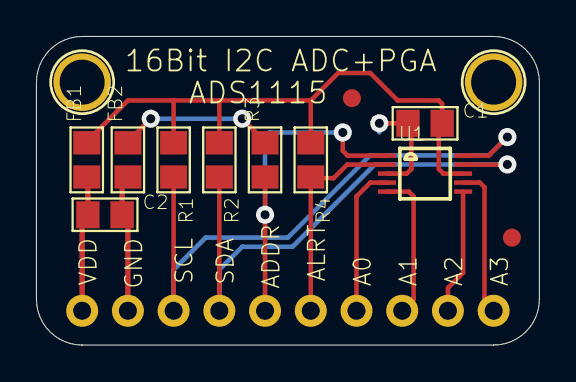
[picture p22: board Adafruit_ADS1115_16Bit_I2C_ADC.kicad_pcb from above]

Board: 2 copper layers, 27.9 x 17.1 mm, 14 parts (0 on the bottom side), 12 nets.

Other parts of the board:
FID1, FID2: FIDUCIAL""; FIDUCIAL_1MM
U$13, U$14: MOUNTINGHOLE2.5; MOUNTINGHOLE_2.5_PLATED

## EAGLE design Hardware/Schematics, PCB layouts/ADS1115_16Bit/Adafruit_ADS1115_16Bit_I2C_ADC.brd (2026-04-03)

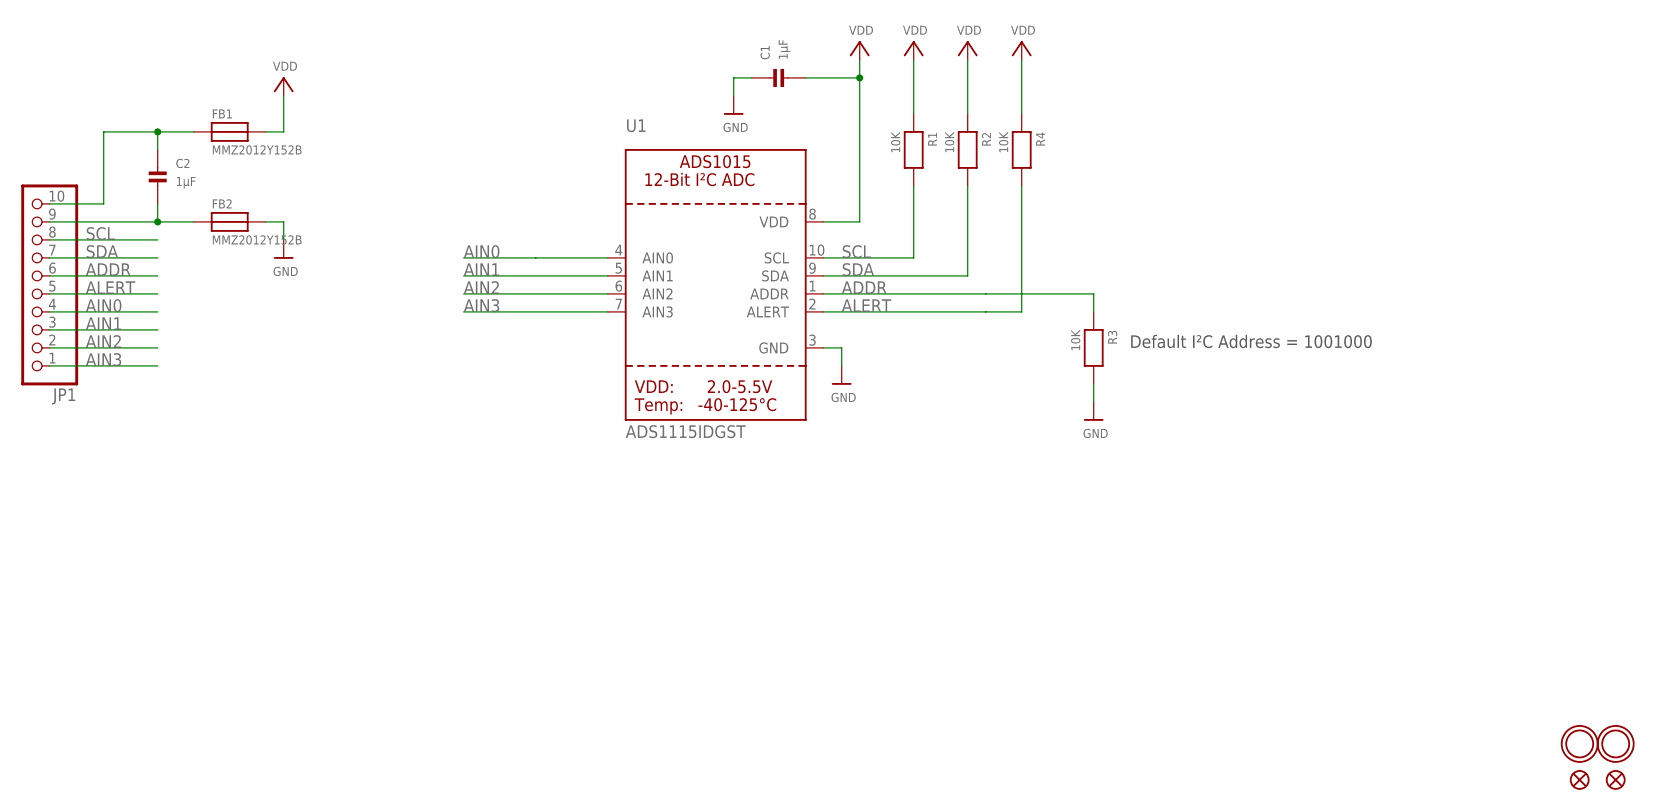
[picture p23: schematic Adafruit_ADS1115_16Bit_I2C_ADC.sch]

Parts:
C1, C2: 1µF; 0805
FB1, FB2: MMZ2012Y152B; 0805
FID1, FID2: FIDUCIAL""; FIDUCIAL_1MM
JP1: HEADER-1X1070MIL; 1X10_ROUND70
R1, R2, R3, R4: 10K; 0805
U1: ADS1115IDGST; MSOP10
U$13, U$14: MOUNTINGHOLE2.5; MOUNTINGHOLE_2.5_PLATED

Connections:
ADDR: JP1.6, R3.1, U1.1 (ADDR)
AIN0: JP1.4, U1.4 (AIN0)
AIN1: JP1.3, U1.5 (AIN1)
AIN2: JP1.2, U1.6 (AIN2)
AIN3: JP1.1, U1.7 (AIN3)
ALERT: JP1.5, R4.2, U1.2 (ALERT)
GND: C1.1, FB2.2, R3.2, U1.3 (GND)
unnamed: C2.1, FB1.1, JP1.10
unnamed: C2.2, FB2.1, JP1.9
SCL: JP1.8, R1.2, U1.10 (SCL)
SDA: JP1.7, R2.2, U1.9 (SDA)
VDD: C1.2, FB1.2, R1.1, R2.1, R4.1, U1.8 (VDD)

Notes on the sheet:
Default I²C Address = 1001000

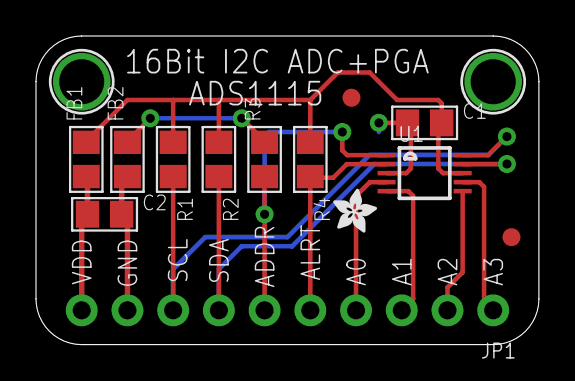
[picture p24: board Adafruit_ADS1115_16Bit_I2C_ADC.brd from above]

Board: 2 copper layers, 27.9 x 17.1 mm, 16 parts (1 on the bottom side), 12 nets.

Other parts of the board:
U$15: ADAFRUIT_TEXT_20MM
U$16: ADAFRUIT_2.5MM

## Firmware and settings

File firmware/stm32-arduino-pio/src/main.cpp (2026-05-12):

/**
 * Port song song với firmware HAL (`firmware/stm32-hal-cmake/Core/Src/main.c`):
 * TIM3 100 Hz tick, PWM bơm/van 1 kHz qua TIM2 (analogWrite trên PA0/PA1),
 * đọc ADS1115, stream UART, FSM + LED.
 *
 * Lưu ý: PA0=TIM2_CH1, PA1=TIM2_CH2 → analogWrite() chiếm TIM2 cho PWM 1 kHz,
 * nên ngắt 100 Hz phải dùng timer khác (chọn TIM3 vì cũng general-purpose,
 * không vướng chân nào đang sử dụng).
 */
#include <Arduino.h>
#include <HardwareTimer.h>
#include <Wire.h>

extern "C" {
#include "board_config.h"
#include "bp_fsm.h"
#include "pressure.h"
}

#include "ads1115.h"
#include "board_pins.h"
#include "led_hmi.h"
#include "uart_proto.h"

/* TIM3 dùng cho ngắt 100 Hz; TIM2 để analogWrite() PWM 1 kHz lên PA0/PA1. */
static HardwareTimer tim_tick(TIM3);

static volatile bool g_tick_100hz = false;

static Ads1115_Handle g_ads;

static void tick_100hz_callback(void)
{
    g_tick_100hz = true;
}

/** Ánh xạ % logic FSM (0=giữ áp … 100=xả max) → % PWM chân van. */
static int valve_logic_to_pin_pct(uint32_t logic_pct)
{
    if (logic_pct > 100u)
        logic_pct = 100u;
    const int seal = (int)VALVE_PIN_AT_LOGIC_SEAL;
    const int vent = (int)VALVE_PIN_AT_LOGIC_VENT;
    int pin = seal + (vent - seal) * (int)logic_pct / 100;
    if (pin < 0)
        pin = 0;
    if (pin > 100)
        pin = 100;
    return pin;
}

static void apply_pwm_outputs(void)
{
    uint32_t pump = bp_fsm_get_pump_pwm_percent();
    uint32_t valve_logic = bp_fsm_get_valve_pwm_percent();
    if (pump > 100u) pump = 100u;
    if (valve_logic > 100u) valve_logic = 100u;
    const int valve_pin = valve_logic_to_pin_pct(valve_logic);
    /* 10-bit: 0–1023 ~ 0–100 % (tương đương HAL ARR=999, compare=pump*10) */
    analogWrite(PIN_PWM_PUMP, (int)((pump * 1023u) / 100u));
    analogWrite(PIN_PWM_VALVE, (int)(((uint32_t)valve_pin * 1023u) / 100u));
}

void setup(void)
{
    pinMode(PIN_BTN_START, INPUT_PULLUP);
    pinMode(PIN_BTN_STOP, INPUT_PULLUP);
    pinMode(PIN_BTN_HIGH, INPUT_PULLUP);

    pinMode(PIN_LED_RED, OUTPUT);
    pinMode(PIN_LED_GREEN, OUTPUT);
    pinMode(PIN_LED_YELLOW, OUTPUT);
    digitalWrite(PIN_LED_RED, LOW);
    digitalWrite(PIN_LED_GREEN, LOW);
    digitalWrite(PIN_LED_YELLOW, LOW);

    Wire.setSCL(PIN_I2C_SCL);
    Wire.setSDA(PIN_I2C_SDA);
    Wire.begin();
    Wire.setClock(100000);

    uart_proto_init();

    ads1115_init(&g_ads);

    bp_fsm_init();

    /* PWM bơm/van trên TIM2 (PA0/PA1) — set TRƯỚC khi cấu hình TIM3 tick,
     * vì analogWriteFrequency() trong STM32duino reconfig timer của các pin
     * đã analogWrite. Gọi đúng thứ tự để khỏi đụng vào TIM3. */
    analogWriteFrequency(1000u);
    analogWriteResolution(10);
    /* Ghi PWM theo cùng ánh xạ FSM→chân van (tránh lệch một nhịp với raw 0). */
    apply_pwm_outputs();

    tim_tick.setOverflow(100, HERTZ_FORMAT);
    tim_tick.attachInterrupt(tick_100hz_callback);
    tim_tick.resume();

    uart_proto_send_line("A,IDLE\r\n");
}

static uint32_t g_seq = 0;
static BpState g_prev_state = BP_STATE_IDLE;
static float g_last_valid_pressure_mmhg = 0.0f;

static const char *error_reason_line(BpErrorReason reason)
{
    switch (reason) {
    case BP_ERROR_I2C_SENSOR:
        return "E,SENSOR_I2C\r\n";
    case BP_ERROR_OVERPRESSURE:
        return "E,OVERPRESSURE\r\n";
    case BP_ERROR_LEAK:
        return "E,LEAK\r\n";
    case BP_ERROR_NONE:
    default:
        return "E,ERROR\r\n";
    }
}

void loop(void)
{
    uart_proto_poll_rx();

    if (!g_tick_100hz)
        return;
    g_tick_100hz = false;

    int start = digitalRead(PIN_BTN_START) == LOW ? 1 : 0;
    int stop = digitalRead(PIN_BTN_STOP) == LOW ? 1 : 0;
    int high = digitalRead(PIN_BTN_HIGH) == LOW ? 1 : 0;

    int16_t counts = 0;
    int rc = ads1115_read_channel0_counts(&g_ads, &counts);
    if (rc != 0)
        bp_fsm_sensor_i2c_fail();
    else
        bp_fsm_sensor_i2c_ok();

    float p_mmhg = g_last_valid_pressure_mmhg;
    if (rc == 0) {
        p_mmhg = pressure_counts_to_mmhg(counts);
        g_last_valid_pressure_mmhg = p_mmhg;
    }
    uint32_t now = millis();

    bp_fsm_on_tick(now, p_mmhg, start, stop, high);

    /* PWM + LED ngay sau FSM: Serial.write (USB CDC) có thể block lâu khi host không
     * đọc kịp — nếu gửi UART trước apply_pwm thì bơm/van kẹt ở duty tick trước. */
    apply_pwm_outputs();
    led_hmi_task(bp_fsm_led_hmi_state());

    BpState stt = bp_fsm_get_state();
    /* Gửi A/E trước S trong cùng tick đổi trạng thái — dễ thấy trên monitor/plotter. */
    if (stt != g_prev_state) {
        if (stt == BP_STATE_INFLATE_SLOW_LISTEN)
            uart_proto_send_line("A,INFLATE_SLOW\r\n");
        else if (stt == BP_STATE_INFLATE_TO_MARGIN)
            uart_proto_send_line("A,INFLATE_MARGIN\r\n");
        else if (stt == BP_STATE_DEFLATE_MEASURE)
            uart_proto_send_line("A,DEFLATE\r\n");
        else if (stt == BP_STATE_FAST_DEFLATE)
            uart_proto_send_line("A,FAST_DEFLATE\r\n");
        else if (stt == BP_STATE_DONE)
            uart_proto_send_line("E,MEAS_END\r\n");
        else if (stt == BP_STATE_ERROR)
            uart_proto_send_line(error_reason_line(bp_fsm_get_error_reason()));
        else if (stt == BP_STATE_IDLE_VENT)
            uart_proto_send_line("A,IDLE_VENT\r\n");
        else if (stt == BP_STATE_IDLE && g_prev_state != BP_STATE_IDLE)
            uart_proto_send_line("A,IDLE\r\n");
    }

    float dps = bp_fsm_get_last_dp_dt_mmhg_s();
    int dp_centi = (int)(dps * 100.f + (dps >= 0.f ? 0.5f : -0.5f));
    if (dp_centi > 32000)
        dp_centi = 32000;
    if (dp_centi < -32000)
        dp_centi = -32000;

    uart_proto_send_sample(g_seq++, now, p_mmhg, rc, counts,
                           (int)stt,
                           (int)bp_fsm_get_pump_pwm_percent(),
                           (int)bp_fsm_get_valve_pwm_percent(),
                           start, stop, high, dp_centi);

    g_prev_state = stt;
}

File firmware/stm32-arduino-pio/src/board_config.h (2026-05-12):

/**
 * Hằng số ứng dụng (áp suất, timeout, PWM %) — dùng chung bp_fsm / pressure.
 * Map chân nằm trong board_pins.h (Arduino).
 */
#ifndef BOARD_CONFIG_H
#define BOARD_CONFIG_H

#include <stdint.h>

#define UART_BAUD 115200u

/* ADS1115 ADDR→GND = 0x48 (Wire dùng địa chỉ 7-bit) */
#define ADS1115_I2C_ADDR_7BIT ((uint8_t)0x48u)

#define PRESSURE_SAFE_MAX_MMHG           185.0f
/** Giới clamp cho lệnh UART `SAF` / `SAFH` (mmHg). */
#define PRESSURE_SAFE_UART_MIN_MMHG      120.0f
#define PRESSURE_SAFE_UART_MAX_MMHG      300.0f
#define LEAK_TIMEOUT_MS                  10000u
#define LEAK_MIN_RISE_MMHG               10.0f
#define LEAK_CONFIRM_MS                  1500u
#define BP_I2C_FAIL_THRESH               50u
#define SAF_OVERPRESSURE_DEBOUNCE_MS     300u
#define SAF_OVERPRESSURE_IMMEDIATE_MARGIN_MMHG 8.0f
#define INFLATE_FALLBACK_TARGET_MMHG     180.0f
#define INFLATE_FALLBACK_AFTER_MS        120000u
#define TARGET_MARGIN_DEFAULT_MMHG       40.0f

#define TARGET_PRESSURE_RATE_MMHG_S      10.0f
/** Tốc độ giảm áp mặc định trong DEFLATE_MEASURE (mmHg/s). Nhanh hơn Omron điển hình (~2.5–4), vẫn trong vùng đo dao động ổn định. WebApp: `DR,<rate>`. */
#define DEFLATE_SLOW_RATE_MMHG_S         8.0f
/** Clamp cho lệnh UART `DR,...` (mmHg/s). */
#define DEFLATE_SLOW_RATE_UART_MIN_MMHG_S  2.5f
#define DEFLATE_SLOW_RATE_UART_MAX_MMHG_S  10.0f
/** Hệ số P servo van (trên dp_dt đã lọc EMA). */
#define DEFLATE_SLOW_VALVE_ERR_GAIN      1.68f
/** EMA trên dp_dt trong DEFLATE_MEASURE (0–1). Thấp hơn → lọc nhiễu, van ít giật vùng ~150–170. */
#define DEFLATE_SLOW_DP_EMA_ALPHA        0.34f
/** Tích phân sai số tốc độ (err = dp_ema + rate, mmHg/s): bù khi lâu không đạt rate. */
#define DEFLATE_SLOW_INTEGRAL_KI         0.70f
/** Trần tích phân ∫(err·dt) với err (mmHg/s); thặng dư tích lũy khi xả chậm hơn setpoint. */
#define DEFLATE_SLOW_INTEGRAL_CAP_MMHG   32.f
/** Khi err âm (xả quá nhanh): co tích phân để tránh wind-up. */
#define DEFLATE_SLOW_INTEGRAL_DECAY      0.88f
/** Chỉ tích phân khi err > ngưỡng (lọc nhiễu gần setpoint). */
#define DEFLATE_SLOW_INTEGRAL_ERR_ON_MMHGS   0.12f
/** err âm hơn ngưỡng này → co tích phân (rộng hơn → ít co vì nhiễu dp). */
#define DEFLATE_SLOW_INTEGRAL_ERR_OFF_MMHGS  0.24f
/** Tích phân ≥ ngưỡng → cho phép bước van lớn hơn (đuổi kịp setpoint). */
#define DEFLATE_SLOW_INTEGRAL_BOOST_THRESH_MMHG  2.35f
#define DEFLATE_SLOW_VALVE_MAX_STEP_BOOST      8u
/** Ngưỡng áp cuff (mmHg) coi là “cực cao”: chỉ vùng này dùng CAP_HIGH phẳng (ΔP lớn → dễ xả vèo).
 *  Trước đây =135 khiến mọi áp ≥135 (gồm ~150) cùng một trần van quá thấp → ~0.5 mmHg/s. */
#define DEFLATE_SLOW_CAP_PRESSURE_MMHG_HIGH  172.0f
#define DEFLATE_SLOW_CAP_PRESSURE_MMHG_LOW    48.0f
/** Áp gối (mmHg): trên break nội suy từ cap_hi; dưới break nội suy nhanh tới cap_lo (bám mmHg/s khi cuff ~<160). */
#define DEFLATE_SLOW_CAP_CURVE_BREAK_MMHG    162.0f
/** Trần % logic van (nội suy theo áp cuff): cuff cao → cap_hi (ít mở); cuff giảm dần → nội suy tới cap_lo (mở nhiều hơn). */
#define DEFLATE_SLOW_VALVE_PCT_CAP_HIGH       47u
#define DEFLATE_SLOW_VALVE_PCT_CAP_LOW        80u
/** Trần van tại áp = DEFLATE_SLOW_CAP_CURVE_BREAK_MMHG (nối hai đoạn cong). */
#define DEFLATE_SLOW_VALVE_PCT_AT_BREAK       58u
/** Nhân thêm lên err_gain khi cuff thấp (chỉ áp dụng dưới DEFLATE_SLOW_ERR_GAIN_LOWPRESS_BELOW_MMHG). */
#define DEFLATE_SLOW_VALVE_ERR_GAIN_LOWPRESS_MULT  1.08f
/** Chỉ tăng gain vùng áp rất thấp; tránh hunt khi vừa qua BREAK (~160). */
#define DEFLATE_SLOW_ERR_GAIN_LOWPRESS_BELOW_MMHG  92.0f
/** Giảm nhẹ nhánh PI khi đã có feedforward (tránh overshoot / dao động). */
#define DEFLATE_SLOW_PI_ON_FF_SCALE           0.82f
/** Feedforward: mẫu số áp thấp (mmHg) — nhỏ hơn p_lo → pos tăng nhanh hơn khi cuff giảm. */
#define DEFLATE_SLOW_FF_PRESSURE_REF_LO       52.0f
/** Feedforward: phần khoảng [min,vmax] mở “mặc định” (0–1). */
#define DEFLATE_SLOW_FF_FRAC_OF_SPAN          0.985f
/** Sàn pos tối đa (sau ramp) khi cuff thấp — ramp DEFLATE_SLOW_FF_FLOOR_RAMP_MM tránh nhảy tại BREAK. */
#define DEFLATE_SLOW_FF_POS_FLOOR_BELOW_BREAK 0.78f
/** Khoảng mmHg dưới BREAK để sàn FF tăng dần 0→FLOOR (smoothstep); hết 0 tại BREAK, đủ ở ~110. */
#define DEFLATE_SLOW_FF_FLOOR_RAMP_MM         48.0f
/** Smoothstep cuff: dải hẹp quanh ~170 mmHg để pos_sfloor tăng nhanh (trước đây 176→150 quá dài → dưới 170 xả chậm dần). */
#define DEFLATE_SLOW_FF_SMOOTH_FLOOR_CUFF_HI_MMHG    174.0f
#define DEFLATE_SLOW_FF_SMOOTH_FLOOR_CUFF_LO_MMHG    168.0f
#define DEFLATE_SLOW_FF_SMOOTH_FLOOR_AT_HI           0.11f
#define DEFLATE_SLOW_FF_SMOOTH_FLOOR_AT_LO           0.42f
/** Feedforward: cuff ≥ p_hi: pos tối thiểu (vẫn thận trọng ở ΔP lớn). */
#define DEFLATE_SLOW_FF_POS_MIN_ABOVE_P_HI    0.11f
/** Bước slew van tối đa/tick khi cuff < DEFLATE_SLOW_ERR_GAIN_LOWPRESS_BELOW_MMHG (100 Hz). */
#define DEFLATE_SLOW_VALVE_MAX_STEP_LOWPRESS  7u
/** DEFLATE_MEASURE: áp ≤ ngưỡng này (liên tục debounce) → DONE (không dùng FAST_DEFLATE). */
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

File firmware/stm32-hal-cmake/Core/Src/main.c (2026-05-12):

#include "stm32f1xx_hal.h"

#include "board_config.h"
#include "ads1115.h"
#include "pressure.h"
#include "bp_fsm.h"
#include "uart_proto.h"
#include "led_hmi.h"

I2C_HandleTypeDef hi2c1;
UART_HandleTypeDef huart1;
TIM_HandleTypeDef htim2;
TIM_HandleTypeDef htim3;

static Ads1115_Handle ads;
static volatile uint8_t g_tick_100hz = 0;

static void Error_Handler(void)
{
    __HAL_RCC_GPIOB_CLK_ENABLE();
    GPIO_InitTypeDef g = {0};
    g.Pin = LED_RED_PIN;
    g.Mode = GPIO_MODE_OUTPUT_PP;
    g.Speed = GPIO_SPEED_FREQ_LOW;
    HAL_GPIO_Init(LED_RED_PORT, &g);
    while (1) {
        HAL_GPIO_TogglePin(LED_RED_PORT, LED_RED_PIN);
        HAL_Delay(120);
    }
}

void SystemClock_Config(void)
{
    RCC_OscInitTypeDef oc = {0};
    RCC_ClkInitTypeDef cc = {0};

    oc.OscillatorType = RCC_OSCILLATORTYPE_HSE;
    oc.HSEState = RCC_HSE_ON;
    oc.HSEPredivValue = RCC_HSE_PREDIV_DIV1;
    oc.HSIState = RCC_HSI_ON;
    oc.PLL.PLLState = RCC_PLL_ON;
    oc.PLL.PLLSource = RCC_PLLSOURCE_HSE;
    oc.PLL.PLLMUL = RCC_PLL_MUL9;
    if (HAL_RCC_OscConfig(&oc) != HAL_OK)
        Error_Handler();

    cc.ClockType = RCC_CLOCKTYPE_HCLK | RCC_CLOCKTYPE_SYSCLK |
                   RCC_CLOCKTYPE_PCLK1 | RCC_CLOCKTYPE_PCLK2;
    cc.SYSCLKSource = RCC_SYSCLKSOURCE_PLLCLK;
    cc.AHBCLKDivider = RCC_SYSCLK_DIV1;
    cc.APB1CLKDivider = RCC_HCLK_DIV2;
    cc.APB2CLKDivider = RCC_HCLK_DIV1;
    if (HAL_RCC_ClockConfig(&cc, FLASH_LATENCY_2) != HAL_OK)
        Error_Handler();
}

static void MX_GPIO_Init(void)
{
    GPIO_InitTypeDef g = {0};
    __HAL_RCC_GPIOA_CLK_ENABLE();
    __HAL_RCC_GPIOB_CLK_ENABLE();

    g.Mode = GPIO_MODE_INPUT;
    g.Pull = GPIO_PULLUP;
    g.Pin = BTN_START_PIN;
    HAL_GPIO_Init(BTN_START_PORT, &g);
    g.Pin = BTN_STOP_PIN;
    HAL_GPIO_Init(BTN_STOP_PORT, &g);
    g.Pin = BTN_HIGH_PIN;
    HAL_GPIO_Init(BTN_HIGH_PORT, &g);

    g.Mode = GPIO_MODE_OUTPUT_PP;
    g.Pull = GPIO_NOPULL;
    g.Speed = GPIO_SPEED_FREQ_LOW;
    g.Pin = LED_RED_PIN | LED_GREEN_PIN | LED_YELLOW_PIN;
    HAL_GPIO_Init(LED_RED_PORT, &g);

    HAL_GPIO_WritePin(LED_RED_PORT, LED_RED_PIN, GPIO_PIN_RESET);
    HAL_GPIO_WritePin(LED_GREEN_PORT, LED_GREEN_PIN, GPIO_PIN_RESET);
    HAL_GPIO_WritePin(LED_YELLOW_PORT, LED_YELLOW_PIN, GPIO_PIN_RESET);
}

static void MX_I2C1_Init(void)
{
    hi2c1.Instance = I2C1;
    hi2c1.Init.ClockSpeed = 400000;
    hi2c1.Init.DutyCycle = I2C_DUTYCYCLE_2;
    hi2c1.Init.OwnAddress1 = 0;
    hi2c1.Init.AddressingMode = I2C_ADDRESSINGMODE_7BIT;
    hi2c1.Init.DualAddressMode = I2C_DUALADDRESS_DISABLE;
    hi2c1.Init.GeneralCallMode = I2C_GENERALCALL_DISABLE;
    hi2c1.Init.NoStretchMode = I2C_NOSTRETCH_DISABLE;
    if (HAL_I2C_Init(&hi2c1) != HAL_OK)
        Error_Handler();
}

static void MX_USART1_UART_Init(void)
{
    huart1.Instance = USART1;
    huart1.Init.BaudRate = UART_BAUD;
    huart1.Init.WordLength = UART_WORDLENGTH_8B;
    huart1.Init.StopBits = UART_STOPBITS_1;
    huart1.Init.Parity = UART_PARITY_NONE;
    huart1.Init.Mode = UART_MODE_TX_RX;
    huart1.Init.HwFlowCtl = UART_HWCONTROL_NONE;
    if (HAL_UART_Init(&huart1) != HAL_OK)
        Error_Handler();
}

static void MX_TIM2_Init(void)
{
    TIM_MasterConfigTypeDef sm = {0};

    /* APB1=36 MHz → TIM2CLK=72 MHz: PSC=7199, ARR=99 → 100 Hz */
    htim2.Instance = TIM2;
    htim2.Init.Prescaler = 7199u;
    htim2.Init.CounterMode = TIM_COUNTERMODE_UP;
    htim2.Init.Period = 99u;
    htim2.Init.ClockDivision = TIM_CLOCKDIVISION_DIV1;
    if (HAL_TIM_Base_Init(&htim2) != HAL_OK)
        Error_Handler();

    sm.MasterOutputTrigger = TIM_TRGO_RESET;
    sm.MasterSlaveMode = TIM_MASTERSLAVEMODE_DISABLE;
    HAL_TIMEx_MasterConfigSynchronization(&htim2, &sm);
}

static void MX_TIM3_PWM_Init(void)
{
    TIM_OC_InitTypeDef oc = {0};

    /* TIM3CLK=72 MHz: PSC=71, ARR=999 → 1 kHz PWM */
    htim3.Instance = TIM3;
    htim3.Init.Prescaler = 71u;
    htim3.Init.CounterMode = TIM_COUNTERMODE_UP;
    htim3.Init.Period = 999u;
    htim3.Init.ClockDivision = TIM_CLOCKDIVISION_DIV1;
    if (HAL_TIM_PWM_Init(&htim3) != HAL_OK)
        Error_Handler();

    oc.OCMode = TIM_OCMODE_PWM1;
    oc.Pulse = 0;
    oc.OCPolarity = TIM_OCPOLARITY_HIGH;
    oc.OCFastMode = TIM_OCFAST_DISABLE;
    HAL_TIM_PWM_ConfigChannel(&htim3, &oc, PWM_MOTOR_CHANNEL);
    oc.Pulse = 0;
    HAL_TIM_PWM_ConfigChannel(&htim3, &oc, VALVE_CHANNEL);
}

static void apply_pwm_outputs(void)
{
    uint32_t pump = bp_fsm_get_pump_pwm_percent();
    uint32_t valve = bp_fsm_get_valve_pwm_percent();
    if (pump > 100u) pump = 100u;
    if (valve > 100u) valve = 100u;
    __HAL_TIM_SET_COMPARE(&htim3, PWM_MOTOR_CHANNEL, pump * 10u);
    __HAL_TIM_SET_COMPARE(&htim3, VALVE_CHANNEL, valve * 10u);
}

void HAL_TIM_PeriodElapsedCallback(TIM_HandleTypeDef *htim)
{
    if (htim->Instance == TIM2)
        g_tick_100hz = 1u;
}

void HAL_UART_RxCpltCallback(UART_HandleTypeDef *huart)
{
    uart_proto_rx_callback(huart);
}
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

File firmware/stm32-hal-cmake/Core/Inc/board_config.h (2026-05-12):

/**
 * Pin map — Blue Pill STM32F103C8T6 (hoặc tương đương medium-density).
 * UART1: PA9 TX, PA10 RX | I2C1: PB6 SCL, PB7 SDA | TIM3 PWM: PA6 motor, PA7 valve
 */
#ifndef BOARD_CONFIG_H
#define BOARD_CONFIG_H

#include <stdint.h>

/* --- UART --- */
#define UART_BAUD           115200u

/* --- I2C ADS1115 (địa chỉ ADDR → GND = 0x48) --- */
#define ADS1115_I2C_ADDR    (0x48u << 1) /* HAL dùng 8-bit */

/* --- Buttons: active LOW, internal pull-up --- */
#define BTN_START_PORT      GPIOA
#define BTN_START_PIN       GPIO_PIN_3
#define BTN_STOP_PORT       GPIOA
#define BTN_STOP_PIN        GPIO_PIN_4
#define BTN_HIGH_PORT       GPIOA
#define BTN_HIGH_PIN        GPIO_PIN_5

/* --- LEDs — schematic D401/D402/D403: PB13 / PB14 / PB15 --- */
#define LED_RED_PORT        GPIOB
#define LED_RED_PIN         GPIO_PIN_13
#define LED_GREEN_PORT      GPIOB
#define LED_GREEN_PIN       GPIO_PIN_14
#define LED_YELLOW_PORT     GPIOB
#define LED_YELLOW_PIN      GPIO_PIN_15

/* --- PWM pump / valve (TIM3) --- */
#define PWM_TIM             TIM3
#define PWM_MOTOR_CHANNEL   TIM_CHANNEL_1 /* PA6 */
#define VALVE_CHANNEL       TIM_CHANNEL_2 /* PA7 */

/* --- Safety / physics (hiệu chỉnh thực tế) --- */
#define PRESSURE_SAFE_MAX_MMHG       175.0f
#define PRESSURE_SAFE_UART_MIN_MMHG  120.0f
#define PRESSURE_SAFE_UART_MAX_MMHG  300.0f
#define LEAK_TIMEOUT_MS             10000u
#define INFLATE_FALLBACK_TARGET_MMHG 175.0f   /* khi không có lệnh T,... */
#define INFLATE_FALLBACK_AFTER_MS   120000u    /* 2 phút chờ lệnh WebApp */
#define TARGET_MARGIN_DEFAULT_MMHG  40.0f     /* WebApp gửi đích = P_sys_est + margin */

#define TARGET_PRESSURE_RATE_MMHG_S  10.0f    /* bơm chậm */

#define DEFLATE_SLOW_RATE_MMHG_S     3.0f     /* servo van */

#define PUMP_PWM_MIN                 5u
#define PUMP_PWM_MAX                 100u

#define VALVE_CLOSED_DUTY            0u       /* 0% = đóng (điều chỉnh nếu NC/NO ngược) */
#define VALVE_FULL_OPEN_DUTY         100u

/**
 * Chuyển đổi MPX5050GP @ 5V → mmHg (xấp xỉ). Hiệu chỉnh OFFSET_MMHG / SCALE với đồng hồ áp.
 * Giả định ADS1115 PGA ±4.096 V → LSB = 125 µV (đặt trong ads1115 driver).
 */
#define PRESSURE_ADC_OFFSET_COUNTS   (-13312) /* placeholder — HIỆU CHỈNH */
#define PRESSURE_ADC_SCALE_MMHG_PER_COUNT (280.0f / 26000.0f) /* placeholder — hiệu chỉnh thực tế */

#endif /* BOARD_CONFIG_H */

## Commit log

2026-03-20 Create .gitignore for multiple development environments
    Added a comprehensive .gitignore file for C/C++, STM32, Altium Designer, KiCad, LTSpice, and general OS files.
2026-03-21 Tạo file word thử
    [OscilloBP Monitor.kicad_pcb, OscilloBP Monitor.kicad_sch]
2026-03-22 Tìm linh kiện upload
    [OscilloBP Monitor.kicad_pcb, OscilloBP Monitor.kicad_sch]
2026-04-03 Thêm schematic.pdf
    [Adafruit_ADS1115_16Bit_I2C_ADC.brd, Adafruit_ADS1115_16Bit_I2C_ADC.kicad_pcb, Adafruit_ADS1115_16Bit_I2C_ADC.kicad_sch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]
2026-05-10 Thêm firmware PlatformIO, webapp và cập nhật layout KiCad/Gerber
    - Firmware STM32 (ADS1115, FSM đo huyết áp, UART)
    - Software/webapp và tài liệu
    - Di chuyển project OscilloBP Monitor vào thư mục con, Gerber
    - Gỡ backup zip và schematic cũ khỏi repo
    [OscilloBP Monitor-B_Cu.gbl, OscilloBP Monitor-B_Mask.gbs, OscilloBP Monitor-B_Silkscreen.gbo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]
2026-05-10 Firmware: migrate to STM32Cube CMake for STM32F103C8T6
    Replace PlatformIO with CMake + HAL/CMSIS FetchContent, Core layout,
    64 KiB linker, CMSIS core headers, and documentation updates.
    [ads1115.c, board_config.h, bp_fsm.c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]
2026-05-12 Relocate HAL firmware to firmware/stm32-hal-cmake
2026-05-12 Add STM32 Arduino (PlatformIO) firmware and refresh README paths
2026-05-12 fix(uart): print sample mmHg without float printf; send A/E before S
    Avoid newlib nano %f (empty mmHg on serial). Emit state lines before
    telemetry on transitions so errors show clearly in the monitor.
    [main.c, main.cpp, uart_proto.c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]
2026-05-12 debug(i2c): add I2C scanner and raw-counts logging in firmware
    - setup() quét bus I2C @100 kHz trên PB6/PB7 và in lại kết quả mỗi 1 s
    cho tới khi user gõ 1 byte trên Serial Monitor mới chạy app, tránh dòng
    S,... trôi mất kết quả scan trước khi mở monitor.
    - loop() in thêm "D,rc=...,counts=..." mỗi 200 ms để xác nhận ADS1115
    thật sự đọc được counts thay đổi, hỗ trợ chẩn đoán hiện tượng pressure
    luôn = 0.00 (do clip âm trong uart_proto_send_sample).
    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
2026-05-12 debug(uart): include ADC counts in sample stream
2026-05-12 hw(pins): remap buttons/PWM and move 100Hz tick to TIM3
    - Buttons → PA11/PA8/PB12, PWM bơm/van → PA0/PA1 (TIM2_CH1/CH2).
    - Đổi tick 100 Hz từ TIM2 sang TIM3 vì TIM2 nay phục vụ analogWrite()
    cho PWM 1 kHz trên PA0/PA1. Thứ tự setup: analogWriteFrequency() trước,
    rồi mới HardwareTimer(TIM3) để tránh reconfig nhầm timer của tick.
2026-05-12 debug(stream): include FSM state, PWM and buttons in S,... line
    Dòng S,... mở rộng thành
    S,seq,t_ms,p_mmHg,rc,counts,fsm,pump%,valve%,btnSPH
    để mỗi tick đều thấy trạng thái FSM, PWM bơm/van và 3 nút (đã đảo
    active-low). Hỗ trợ chẩn đoán hiện tượng "bấm START mà motor không
    chạy" — phân biệt được rơi vào state nào (FAST_DEFLATE do STOP stuck,
    ERROR do I2C, hay đang INFLATE nhưng PWM không lên do nguồn).
    [main.cpp, uart_proto.cpp]
2026-05-12 feat(fsm): pump soft-start and slope cap to mitigate brownout
    Khi motor bơm khởi động kéo dòng inrush gấp 5-10 lần dòng chạy,
    nguồn không đủ gồng sẽ kéo VCC sụt < 3V → STM32 brownout-reset.
    Thêm 3 giới hạn trong bp_fsm.c để giảm di/dt và đỉnh dòng:
    - IDLE→INFLATE: kick khởi đầu giảm từ 15% xuống PUMP_PWM_MIN (5%).
    - Soft-start window: trong PUMP_SOFTSTART_MS (500ms) đầu sau khi rời
    IDLE, kẹp pump_pwm ≤ PUMP_SOFTSTART_CAP_PCT (30%).
    - Slope cap: mọi cập nhật pump_pwm trong các state INFLATE đi qua
    ramp_pump_to() — tối đa ±PUMP_SLOPE_PER_TICK_MAX (1%/tick @100Hz
    = 100%/s) để motor có thời gian vào v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
    [board_config.h, bp_fsm.c]
2026-05-12 Đồng bộ firmware, webapp, báo cáo LaTeX và tài liệu kỹ thuật.
    Thêm Docs/Technical reports (Project_report, plan). Cập nhật Arduino/HAL, giao thức UART, webapp. Gỡ submodule mpx5050-blood-pressure-monitor lồng nhau. Thêm archive nhỏ và backup KiCad.
